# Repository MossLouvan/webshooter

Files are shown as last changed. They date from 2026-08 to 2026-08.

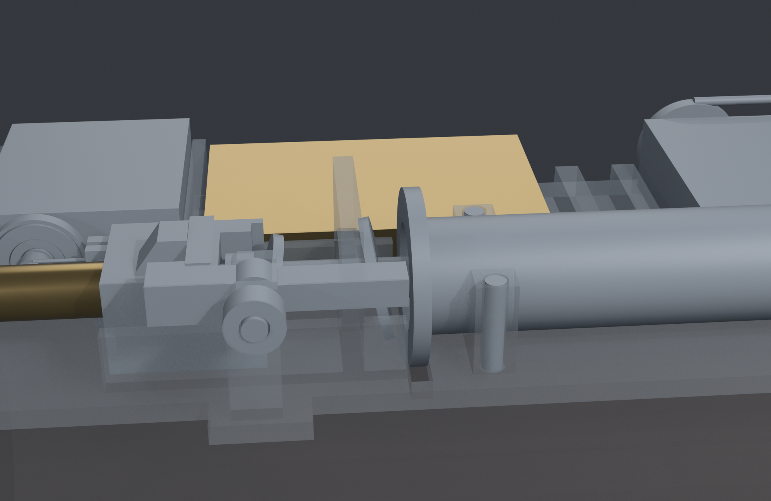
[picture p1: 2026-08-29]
mk2/mk5_02_mechanism.png

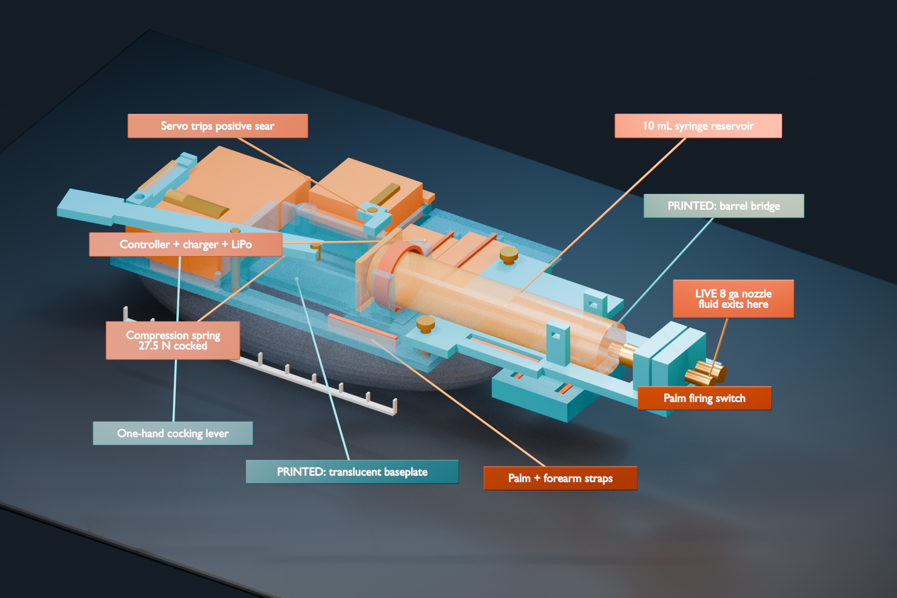
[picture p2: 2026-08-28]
mk2/mk3_viz_01_hero.png

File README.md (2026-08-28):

# Web-Shooter

A wrist-worn device that sprays Beacon Fabri-Tac fabric adhesive to produce a
Spider-Man-style strand. Visual effect only — **it bears no load**.

> **Status: unbuilt, untested, and currently failing its own independent audit.**
> This is a design-in-progress published for reference. Nothing here has been printed,
> assembled, or fired. See [Known failures](#known-failures-mk4) before doing anything else.

## Safety — read before building

This device stores mechanical energy in a compressed spring and uses it to eject a jet of
acetone-thinned contact adhesive at several metres per second.

- **Acetone and Fabri-Tac vapour are flammable.** The mixture is a skin, eye and
  respiratory hazard, and Fabri-Tac bonds to skin. Mix and fire only with strong
  ventilation, away from all ignition sources, wearing sealed goggles, solvent-rated
  (butyl/nitrile) gloves and an organic-vapour respirator.
- **There is no mechanical safety and no firmware in this repo.** The Mk4 sear is
  self-holding; the only thing between the cocked spring and a discharge is a hobby servo
  horn. A servo power-up twitch, brownout, reset, or loose lead can fire it. Any build
  must add a physical sear block or trigger disconnect that is removed by hand, and must
  keep the battery disconnected whenever the spring is cocked and not about to be fired.
  A naively written firmware will fire on boot.
- **Never cock, load, or fire the device while it is on an arm.** Cock with two hands,
  off the arm, muzzle pointed at a disposable backstop. Peak cocking force is ~16 N on a
  4 mm printed tab that sits in the carriage path: if your thumb slips before the sear
  engages, the carriage snaps forward onto your fingers.
- Never point it at a person, animal, face, flame, vehicle or property. Store it uncocked
  (PETG creeps under sustained load and is **not** acetone-resistant; the sear is a
  life-safety part and its layer orientation matters).
- The LiPo has no retention in Mk4. Do not strap an unretained pouch cell against a
  moving carriage and a solvent reservoir; relocate or pocket it.

**No warranty.** This is an experimental personal project published for reference only.
It is not a product, has never been built or bench-tested, and has not been reviewed for
safety by anyone qualified. It is provided "AS IS", without warranty of any kind (see
`LICENSE`). You build, modify, or operate it entirely at your own risk, and the author
accepts no liability for any injury, damage, or loss.

## Layout

Everything lives in `mk2/` (the folder name is historical; it holds Mk3 and Mk4).

| File | What it is |
|---|---|
| `webshooter_mk4.py` | **Current.** Parameterized CadQuery model; exports STEP/STL + `mk4_params.json` |
| `webshooter_mk2.py` | Previous Mk3 model (filename retained from the rebuild target) |
| `verify_independent.py` | Audit harness not written by the geometry author; reprobes the exported solids |
| `mk4_indep.json`, `indep_quick.json` | Independent-audit output for Mk4 / Mk3 — including the failures |
| `DESIGN_NOTES.md` | Design decisions, force and velocity arithmetic, unverified values |
| `BOM_DELTA.md` | What must be bought |
| `*_BRIEF.md` | Design/rebuild briefs written for and with AI coding agents during development; kept for provenance |
| `bl.py`, `build_mk4_viz.py`, `build_blender_viz.py` | Blender scene builder + headless CLI |
| `printed_parts/`, `assembly_stl/`, `mk4_*.stl/step` | Generated geometry |

## Mk4 (current)

Open frame: a curved baseplate strapped to the forearm with components mounted exposed
on top, and a muzzle extending over the back of the hand. A 5 mL syringe acts as
reservoir, pump and seal in one part. A hand-cocked spring is held by a self-holding sear
and released by a hobby servo. Mk4 cut the Luer fitting, the cocking lever and its pins.

**Targets:** ≤25 mm wrist profile · ≥1.5 mL per shot · ≤6 printed parts · ≥1.5 m throw.

### Known failures (Mk4)

`verify_independent.py` on the committed Mk4 geometry reports these; none are fixed yet:

- `baseplate <> switch_pod` overlap 255.95 mm³; `baseplate <> sear` 150.00 mm³;
  `baseplate <> outlet_adapter` 85.88 mm³; `baseplate <> carriage` 18.90 mm³
- carriage → baseplate: 18.90 mm³ interference **at 0.00 mm of travel** (it jams before it moves)
- unsupported islands on baseplate (50.7 mm²), carriage (21.5), outlet_adapter (50.8), switch_pod (60.0)
- with the real 8 ga needle (ID 3.429 mm) the shot needs 0.1705 J but the spring stores 0.1335 J
  — **the design does not have the energy to fire as specified**

Unmodelled and known-doubtful: syringe seal breakaway friction (can consume the whole spring
force), a linear spring that falls below the 5.6 N plunger force at ~11 of 16 mm of stroke
(only ~1.3 mL of 2 mL leaves at pressure), and a 0.5 Pa·s viscosity guess for thinned,
non-Newtonian adhesive. All range figures are indicative only.

## Reproduce

```bash
pip install cadquery                              # Python 3.12 required
python mk2/webshooter_mk4.py                      # writes STEP/STL + mk4_params.json
python mk2/verify_independent.py --quick          # independent audit (defaults to Mk4)
python mk2/verify_independent.py --model webshooter_mk2   # audit the Mk3 model
blender -b --python mk2/build_mk4_viz.py          # Blender 5.2 scene
```

The verifier exits via `os._exit` because CadQuery/OCCT can segfault at interpreter teardown.

## Design history

Mk1 was an enclosure around a 10 mL fragrance pump. Three independent audits found it
over-packed (96% cabin fill), geometrically broken in three parts, and functionally
doubtful — a 0.1 mL dose cannot form a strand. Scrapped and removed from the tree.

Mk2 replaced it with an open frame and a syringe, hitting the size and volume targets,
but audits found the chosen linear actuator was ~100× too slow: for a positive-displacement
pump, exit velocity is fixed by kinematics alone, and a 210:1 gearbox and a jet are
mutually exclusive. Mk3 replaced the drive with a spring and sear; its self-check passed
while the independent harness found jams and overlaps. Mk4 is the response, and still fails.

**Lessons worth keeping:** compute exit velocity and range, not just shot volume; size the
spring on force at end of stroke, not stored energy; do not trust a model's own self-check.

## Requirements

- Python 3.12 + CadQuery 2.8 (`pip install cadquery`)
- Blender 5.2 for visualization (`bl.py` looks for it at the default Windows install path;
  edit `DEFAULT_BLENDER` otherwise)
- CQ-editor for interactive viewing (`pip install cq-editor`), optional

Print in PETG for load-bearing parts (creep resistance; it is not acetone-proof — keep the
solvent path off the printed parts); PLA is fine for fit-test coupons only.

## `bl.py` — Blender scene CLI

Drives a `.blend` headlessly (defaults to the Mk3 visualization; pass `--blend
mk2/webshooter_mk4.blend` for Mk4). Note that `show/hide/isolate/reset` save the file.

```bash
python mk2/bl.py stats                  # counts, bounds, frame range, markers, cameras
python mk2/bl.py ls                     # every object: collection, dims, location
python mk2/bl.py tree                   # collection hierarchy
python mk2/bl.py info sear              # full dump for matching objects
python mk2/bl.py measure syringe sear   # min vertex gap + bbox gap + centre distance
python mk2/bl.py isolate baseplate      # show only these
python mk2/bl.py render --cam hero --frame 46 --res 1920x1280
python mk2/bl.py shot --az 135 --el 20  # render from an arbitrary angle
python mk2/bl.py turntable --frames 24  # orbit sequence
python mk2/bl.py export --fmt glb --only printed
```

Names match loosely: case-insensitive, punctuation-insensitive substrings, and
collection names work anywhere an object name does. `--dry` prints the generated
Blender script instead of running it.

## License

MIT — see `LICENSE`. The disclaimer above applies to the hardware design as well as the code.

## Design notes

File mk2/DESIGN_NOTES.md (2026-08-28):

# Web-Shooter Mk3 design notes

## Exit velocity and range — governing calculation

Mk3 uses a hand-cocked compression spring, a positive sear, and an owned Corona DS239MG servo only to release the sear. The Actuonix L12, Pololu U3V70F6 and DRV8833 are deleted.

For any positive-displacement syringe, force and viscosity do not set the kinematic ceiling. Plunger speed and area ratio do:

```text
10 mL syringe bore               d_p = 15.9 mm
plunger area                     A_p = pi d_p^2 / 4 = 198.556 mm2
3.0 mm effective outlet area     A_o = pi (3.0)^2 / 4 = 7.069 mm2
area ratio                       A_p/A_o = 28.080

2.000 mL stroke                  x = 2000 / 198.556 = 10.073 mm
selected shot time               t = 0.069 s
mean plunger speed               v_p = x/t = 0.14599 m/s
exit velocity                    v_exit = v_p(A_p/A_o) = 4.101 m/s
ideal level 45 degree range      R = v_exit^2/g = 1.715 m
```

The 69 ms shot is deliberate. The rebuild brief's illustrative 0.5 s shot would give only 0.566 m/s and an ideal ballistic range of 0.033 m. Even the final 250 ms limit gives only 1.13 m/s and 0.13 m ideal range. Therefore the explicit **>=1.5 m ballistic target** governs and requires no more than about 74 ms for 2 mL through a 3 mm outlet. Mk3 carries 14.3% ideal-range margin and 181 ms time margin to the hard limits.

The range value is the drag-free 45 degree upper bound, not a promise for adhesive in air. Real strand range must be measured outdoors into a safe backstop. The calculation is printed on every generator run and stored in `verification_report.json` so a slow drive can never pass silently again.

## Fluid and spring sizing

Beacon's Fabri-Tac SDS publishes 8,000 cP (8.0 Pa·s) for the neat adhesive. Mk3 uses the permitted **1:1 Fabri-Tac/acetone starting mixture**. The brief's measured guidance is that this reduces shear viscosity about 16x, to roughly 0.5 Pa·s, while polymer extensional elasticity preserves stringing and acetone flash-off reconcentrates the strand.

The source spring is selected from the owned/buying compression-spring assortment by measurement, not by color or appearance:

```text
maximum OD                     10.0 mm
free length                    39.7 mm
spring rate                    1.94 N/mm
fired installed length         35.6 mm
cocked installed length        25.53 mm
fired preload                  7.95 N
cocked force                   27.50 N
releasable energy              0.179 J
lever mechanical advantage     2.06:1
maximum ideal hand force       13.35 N
```

The releasable energy is below the verifier's 0.25 J safety ceiling. It is enough for the short, wide 8 ga/Luer path only after 1:1 thinning; it is not permission to install a stiffer spring. Bench-select the spring with the multimeter-sized scale/force fixture described below, then confirm 2 mL discharge in <=69 ms with high-frame-rate video. If the measured shot is slower, reduce restriction and seal friction before changing spring energy.

The live nozzle mockup uses the real nominal 8 ga OD of 4.19 mm and a conservative 3.0 mm effective outlet. The capped upper nozzle is visual symmetry only. The syringe Luer, live hub, metal nozzle, and both bridge bores share the named axis `(y=-6.0, z=12.5)`; the verification report asserts 0.000 mm axis and axial connection error.

## Mechanical architecture

Six printed parts are generated:

1. `baseplate` — flat-printing 2.8 mm shallow chord with a continuous perimeter, broad device floors, two forearm strap pairs, spring reaction wall, 24 mm-wide carriage way, open electronics anchors, syringe cradle, and bridge bosses.
2. `barrel_bridge` — continuous 32 mm deck with a 74 mm open syringe/Luer lane, 60 mm rear joint wing, outboard palm strap slots, forward syringe guide, and two bored barrel towers.
3. `spring_carriage` — broad anti-rotation tappet guided on both sides, with spring seat, full plunger pad, closed cocking-pin lug, and sear shoulder.
4. `cocking_lever` — one-hand lever with a 55 mm hand arm and closed M3 drive eye. Its deployed arc retracts the carriage through the full 10.073 mm stroke; the sear holds the load while the lever returns to the stowed position.
5. `servo_sear` — M3-pivoted, thickened around the pivot. The spring load closes into the base boss; the DS239MG horn only trips the unloaded tail.
6. `palm_switch_pod` — 2 mm floor under the owned 12 mm tactile switch, two bounded 26 mm strap slots, and lead-retention holes. It is held by the palm strap rather than floating from the hand.

The baseplate prints flat on its 7,435.6 mm² first layer. It is not a concave shell. Closed-cell neoprene supplies the conformal skin interface. The bridge joint has direct boss-to-deck contact at z=6.2 mm and two M3 heat-set inserts centered at x=112 mm, 6 mm inboard of the base end; no insert pocket breaks out and there is no clamped air gap.

The bridge lane leaves two 6.75 x 3.0 mm continuous side rails through the syringe zone: 40.5 mm² total section before the wider wings and tower roots. This replaces Mk2's two 0.75 mm ligaments. The rear and forward syringe guides have 0.60 mm radial clearance and explicit EPDM retainer geometry. A low rear flange stop reacts the syringe body below the elevated carriage sweep. The complete finger flange is present in the syringe mockup.

The electronics stack is now only the owned 1S LiPo, XIAO ESP32C3, TP4056/DW01 charger, DS239MG servo, hard switch, and wiring. The pouch has a 0.60 mm floor gap, low corner keepers, and no top clamp. Each board rests 0.60 mm above a real floor and is held under an EPDM U-band in broad grooved anchors; USB ends stay open.

## Verification harness

`python webshooter_mk2.py` regenerates the part STEP/STL files, full assembly STEP, every assembly STL mockup, and `verification_report.json`. A passing run performs all of the following:

- prints exit velocity, ideal 45 degree ballistic range, volume, and shot time;
- checks exactly 2.000 mL, <=69 ms, >=1.5 m ideal range, <=0.25 J spring release energy, <=6 printed parts, and <=25 mm wrist profile;
- sweeps the carriage every 0.5 mm through 10.0 mm and at the exact 10.073 mm endpoint;
- checks both intersection volume and true minimum distance for every unordered assembly pair;
- rejects tangency for non-contact pairs and documents every allowed functional contact;
- requires `abs(z_min) < 0.0001 mm` in the real print orientation—there are no epsilon lifts;
- computes first-layer footprint from a real 0.20 mm slab;
- sections every part along X, Y, and Z at nine stations and rejects sampled areas below 2 mm² or sampled ligaments below 1.2 mm;
- tessellates each part, samples actual triangle normals, and reports down-facing area below 45 degrees above the build layer;
- checks straight fluid-path connectivity and tower-bore alignment;
- asserts a named source and envelope for every assembly mockup.

Latest clean audit values are written to the JSON rather than copied as untracked claims. The generated model has 6 valid single-solid parts, a 24.3 mm wrist-zone profile, a 0.400 mm worst-case swept static gap, and zero failures **from its own self-check**. The independent harness (`verify_independent.py --model webshooter_mk2`, output in `indep_quick.json`) disagrees and reports jams and overlaps; that disagreement is what drove Mk4, which still has open failures — see the README.

## Assembly and operation

1. Print the base, bridge, carriage, lever, sear, and switch pod in PETG using their exported local orientations. Do not rotate the base onto its old curved underside.
2. Heat-set the two bridge inserts; install the bridge with direct face contact. Confirm the live Luer/nozzle axis by sight before fitting adhesive.
3. Select and measure the spring. Reject any spring above 10 mm OD, 2.0 N/mm measured rate, 28 N cocked force, or 0.20 J measured release energy.
4. Fit the carriage between the two open rails, install the M3 cocking and pivot pins, and verify the carriage moves the full 10.073 mm by hand with the spring removed.
5. Fit the syringe under the EPDM guide retainer with its finger flange behind the low axial stop. The syringe must lift out after the retainer is released, allowing a second fill/shot after re-cocking.
6. Mount the DS239MG in its M3 cradle. Adjust the horn so it clears the sear except during a commanded trip. The servo must never hold spring load.
7. Route both forearm straps and the palm strap through all modeled slot pairs. The palm strap retains the switch pod.
8. Mix only a small 1:1 charge, away from ignition sources, with strong ventilation and eye protection. Acetone and Fabri-Tac vapors are flammable. Never aim the device at a person, animal, face, flame, vehicle, or property.

## Mandatory bench gates

- With the nozzle removed, confirm carriage travel is >=10.073 mm and no contact occurs at any intermediate position.
- With water, confirm 2.00 mL leaves in <=69 ms. Then repeat with a very small 1:1 adhesive charge into a safe disposable backstop.
- Measure spring force at fired and cocked lengths. Do not exceed the limits above.
- Confirm the LiPo cannot be compressed by straps or retainers and has clearance for swelling.
- Measure the actual owned TP4056, LiPo, switch, EPDM bands, spring and syringe flanges. Items marked `MEASURE` in the report must fit their conservative envelopes before printing the full base.
- Treat 1.715 m as an ideal ballistic ceiling. Record actual strand range and stop if atomization, splashback, clogging, frame cracking, sear bounce, or accidental release occurs.

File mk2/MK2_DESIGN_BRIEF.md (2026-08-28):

# Web-Shooter Mk2 — DESIGN BRIEF

**From:** Claude Code (Fable 5), 2026-08-27
**To:** Codex (full access)
**Status:** clean-sheet redesign. Mk1 is archived at `../archive_mk1/` and is **not** to be reused.

---

## 0. Why Mk1 was scrapped

Mk1 was an **enclosure containing a pump**. It grew to a 118 × 64 × 38 mm box because rigid parts
were stacked orthogonally and walls were wrapped around whatever the total came to. It also fired
only **0.1 mL per shot** (a fragrance pump's dose), which is roughly two orders of magnitude short
of what makes a visible strand. Three independent reviews found it over-engineered, badly packed,
and functionally doubtful.

**Mk2 is a different object: an open frame carrying a projector.**

The builder showed a reference build he wants to match — a flat plate strapped to the forearm,
components mounted exposed on top, and barrels extending forward over the back of the hand. No
shell. That silhouette is the design target, and it is not negotiable.

---

## 1. Design targets, in priority order

1. **Sleek.** Profile at the wrist **≤ 25 mm** above the skin. Nothing may look like a box.
2. **Functional.** It must deliver enough fluid to read as a strand, not a mist. Target
   **≥ 1.5 mL per shot** — at least 15× Mk1.
3. **Simple.** Target **≤ 6 printed parts**. Mk1 had 13.
4. **Buildable** by a student with a Bambu printer, hand tools, and the existing cart.

Where 1 and 2 conflict, say so explicitly and propose the trade rather than silently picking.

---

## 2. Architecture

**Open baseplate, no enclosure.** A curved plate that follows the dorsal forearm, ~3–4 mm thick,
with components bolted to its top face and left exposed. Cable runs and mechanism are visible —
that is the aesthetic, not a compromise.

**Three zones along the arm:**

| Zone | Location | Contents |
|---|---|---|
| Rear | forearm, x ≈ 0–90 | reservoir + drive mechanism |
| Mid | wrist, x ≈ 90–120 | electronics, kept thinnest — this crosses the flex point |
| Front | back of hand, x ≈ 120–190 | barrel bridge + barrels |

The **barrel bridge** is the signature feature. A narrow arm carrying the barrels forward over the
knuckles, so the barrels sit high and point where the hand points. The back of the hand is flat and
unused — exploit it. Keep the bridge narrow so it does not obstruct finger movement, and set the
barrel line so it clears the knuckles when the wrist is neutral.

**Two barrels.** Both are visible; at minimum one is live. Decide whether the second is live
(split flow, two strands) or a dummy for symmetry, and justify it. Symmetry is a legitimate reason
— this is a worn object.

**Straps, not a cuff.** Two strap slots in the baseplate for 25 mm webbing: one across the forearm,
one across the palm/hand. Delete the entire Mk1 elliptical-cuff apparatus. The baseplate's underside
should be a simple concave curve (dorsal forearm crown radius ≈ 50 mm) with a thin foam pad
assumed, not a fitted anthropometric shell.

---

## 3. Fluid system — the part that must actually work

**Use a syringe as reservoir, pump, and seal in one part.**

This is the key simplification. A syringe already is: a sealed reservoir, a positive-displacement
pump, a plunger seal, and a standard Luer outlet. Adopting it deletes the atomizer, both EPDM
glands, the M6 nut, the nozzle block's seal stack, the PTFE thread tape and the moving actuator —
i.e. every leak path in Mk1.

- **Reservoir:** a 10–20 mL plastic syringe, laid along the forearm. Must be **PP/PE with no rubber
  plunger tip** — acetone swells rubber. Parameterize barrel OD and length.
- **Outlet:** Luer taper → short PTFE or PP line → barrel. A blunt dispensing needle in the
  **1.0–1.5 mm** range is the physics-recommended orifice for a coherent jet; the 0.4 mm brass
  nozzle from Mk1 is explicitly **not** the plan (that orifice forces heavy dilution, and dilution
  is what destroys stringing).
- **Fluid:** Beacon Fabri-Tac, **undiluted or thinned no more than 1:0.5**. The concentration is
  what makes it string.

**Drive:** the servo pushes the plunger. The plunger needs tens of millimetres of travel, which a
short horn cannot give, so you need mechanical advantage — a long lever, a rack, a lead screw, or
a cam. **This is the single most important engineering decision in Mk2 and it is yours to make.**

Constraints and known data:
- Corona DS239MG: **4.6 kg·cm at 6 V**, and servodatabase lists its rotation as limited — verify
  and design conservatively. The builder owns **two**.
- Required plunger force is **unknown** and depends on syringe bore, fluid viscosity and orifice.
  Estimate it, show the arithmetic, and state the margin.
- **If the DS239MG cannot do it, say so and specify what to buy instead** (a higher-torque servo, a
  geared DC motor with a lead screw, or a linear actuator). A correct recommendation to buy a
  different actuator is a better outcome than a design that stalls.
- A one-shot-per-fill design is acceptable if it buys sleekness; a multi-shot ratchet is better.
  Choose and justify.

**Refill** must not require disassembly — the syringe should lift out or be reloaded in place.

---

## 4. Electronics

Carry over from Mk1, unchanged and already owned: **XIAO ESP32-C3**, **TP4056 USB-C with DW01
protection**, **EEMB 103454 LiPo**, **12 × 12 mm tactile switch**, 26 AWG silicone wire, JST-PH.
**No MT3608** — the boost was deleted and stays deleted unless your actuator choice forces it back,
in which case flag it loudly.

- Trigger: palm switch, **double-tap within 400 ms**.
- **Do not use GPIO8 or GPIO9** for the switch — GPIO9 is the boot strapping pin.
- A **power switch is required** and does not exist yet. Specify one and give it a mount.
- Boards have **no mounting holes** — design clips or captive pockets.
- USB-C on the TP4056 must be reachable for charging; the XIAO's USB-C must be reachable for
  flashing. On an open frame this is easy — do not squander it.

---

## 5. Deliverables

Work in `mk2/`. Do not touch `../archive_mk1/`.

1. **`webshooter_mk2.py`** — parameterized CadQuery model. Named constants at the top with a
   confidence comment on anything unverified. Exports one STEP and STL per printed part.
2. **A real assembly** — `cadquery.Assembly` with explicit transforms, plus **mockup solids** for
   every purchased item (syringe, servo with horn/lever, LiPo, XIAO, TP4056, switch, barrels,
   straps, and a forearm + hand reference) so the assembly shows how it works. Mockups in a
   separate dict, never exported as printable.
3. **`assembly_stl/`** — every part at its assembly transform, for rendering.
4. **`DESIGN_NOTES.md`** — the actuator decision with its force arithmetic, the profile height
   achieved, part count, what is proxy/estimate/unverified, and a measure-before-printing list.
5. **`BOM_DELTA.md`** — exactly what must be **bought that the builder does not already own**, with
   quantities and why each is needed. Be specific and minimal. He already owns everything in §4
   plus Fabri-Tac, acetone, PTFE tube, EPDM assortment, M3 screws, M3 heat-set inserts (5.0 × 4.0),
   4 × 2 mm magnets, brass 0.4 mm nozzles, glass atomizers, dropper bottles, butyl gloves,
   respirator, goggles.

## 6. Hard requirements — these will be checked

- Every printed part: **exactly one solid**, `isValid()`, and no geometry below its own z = 0.
- **No unintended interference.** Run a pairwise intersection check across all parts *and* mockups
  and report the volumes. Intended contacts must be listed explicitly with a reason. Assume a
  reviewer will run this check without your allow-list — Mk1's did, and found 18 pairs.
- Every mating feature must exist on **both** sides, driven by **shared named constants**. No
  duplicated coordinate literals.
- No declared-but-unused parameters.
- Wrist profile height stated and ≤ 25 mm.
- Shot volume stated and ≥ 1.5 mL.

## 7. Latitude

The zones, the syringe, and the barrel bridge are the concept. **Everything else is yours.** If a
different drive mechanism, a different reservoir, or a different part split serves the three targets
better, take it and explain why. If you conclude a target is unachievable, say which one and what it
would cost to reach — do not quietly miss it.

Three independent reviewers will audit this build and will keep auditing until they have no
substantive findings. Design for that.

Work autonomously. Do not stop to ask questions.

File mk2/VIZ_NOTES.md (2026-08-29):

# Web-Shooter Mk5 visualization

`webshooter_mk5.blend` is a Cycles product-presentation scene generated from
the transformed STLs in `mk5_assembly_stl/`. It opens at the cocked/ready frame
with the labeled hero camera active.

## Presentation design

- Satin/brushed steel distinguishes printed working structure; warm polished
  brass identifies the spring, plunger interfaces, and muzzle.
- The cartridge uses transmissive borosilicate glass. Frosted translucent PETG
  keeps the chassis readable without hiding the mechanism.
- Electronics use graphite polymer, LiPo foil, and green FR4/solder-mask
  materials. The palm switch is matte red rubber.
- Every imported STL has a 0.4 mm, three-segment highlight bevel.
- A four-light studio rig, low-strength environment, and smooth charcoal
  cyclorama provide soft contact shadows and controlled metal/glass reflections.
- The label-free beauty camera uses restrained depth of field. The technical
  camera is fully sharp and retains short, staggered, part-following leaders;
  the baseplate label remains below the device.
- The mechanism camera views the sear/pawl from the open side so the dark servo
  does not wall off the working interface.

## Outputs

- `mk5_00_beauty.png` — label-free portfolio hero.
- `mk5_01_hero.png` — labeled technical hero.
- `mk5_02_mechanism.png` — sear/pawl and spring-drive close-up.
- `mk5_03_plan.png` — top-down assembly layout.
- `mk5_04_firing.png` — fired state and fluid pulse.

All final stills are 2560 × 1600, rendered in Cycles at 256 samples with
denoising and AgX medium-high contrast.

## Regenerate

```powershell
& 'C:\Program Files\Blender Foundation\Blender 5.2\blender.exe' -b --python '.\build_mk5_viz.py'
```

The generator requests OptiX first, CUDA second, and reports a CPU fallback if
neither GPU backend initializes. For quick beauty look-development, set
`MK5_LOOKDEV=1`. To render only one named output, set `MK5_VIEW` to its filename
stem, for example `mk5_02_mechanism`.

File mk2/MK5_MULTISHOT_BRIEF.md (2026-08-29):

# Mk5 — MULTI-SHOT BRIEF

**Status:** Mk4 was rejected NOT READY by two independent acceptance reviews. The builder has
independently identified the same top defect: **it fires once and does not return.** He wants a
mechanism that shoots, re-cocks itself, and shoots again.

This brief is the fix list plus the new requirement. Read it whole before editing anything.

---

## 1. THE NEW REQUIREMENT — multi-shot with self-recock

**Mk4 fires exactly one useful shot per fill, and nobody noticed until two reviewers and the
builder found it separately.** The carriage cocks to a fixed x=31.57 and fires to a fixed x=48.00.
After shot 1 the syringe plunger has advanced 16.43 mm and sits at x=60.00 — beyond anywhere the
carriage can reach. Shot 2 pushes air.

**Mk5 must fire, re-cock, and fire again, repeatedly, until the cartridge is empty.**

### This is a caulk gun

The problem is exactly the one a caulk gun solves: a **fixed-stroke actuator advancing a plunger
incrementally through a one-way grip.** The plunger never retracts — it does not need to. Each
cycle the carriage grips the rod further back, drives it forward one stroke, then releases and
slides back along the now-stationary rod to grip again.

Adopt that. A tilting grip plate, a ratchet and rack, or a one-way roller clutch are all valid;
pick one and justify it. The grip must hold 37 N forward and release cleanly on the return.

### Shot count is a cartridge-size decision

| Cartridge | shots at 2.0 mL |
|---|---|
| 5 mL (Mk4) | 2.5 |
| **10 mL** | **5** |
| 20 mL | 10 |

Mk4 went 10 mL -> 5 mL to cut force and height. With a ratchet the force argument weakens, because
the servo can do the work. **Re-open that choice.** If you go back to 10 mL, say what it costs in
wrist profile and re-check the target (<= 25 mm).

If you reduce shot volume to gain shots, the outlet bore must shrink to hold exit velocity —
`A_o = V / (t · v_exit)`. 1.5 mL -> 3.46 mm bore; 1.0 mL -> 2.83 mm. Do not silently lose range.

### Auto-recock is affordable — I checked before asking

```
recock work            = ½ · 37.42 N · 16.43 mm = 307 N·mm = 0.307 J
DS239MG stall           = 451 N·mm   (4.6 kg·cm at 6 V)
honest continuous (⅓)   = 150 N·mm

torque needed vs servo sweep:
    90°  -> 196 N·mm   too much
   120°  -> 147 N·mm   marginal
   160°  -> 110 N·mm   1.4× margin
   180°  ->  98 N·mm   1.5× margin
```

**A generous sweep (160–180°) through a cam or lever makes recock feasible with the servo he already
owns.** Verify the DS239MG's actual usable rotation — servodatabase lists it as limited, and if it
cannot sweep 160° this whole approach changes.

---

## 2. THE SEAR PROBLEM, AND THE ARCHITECTURE CHOICE

Both reviewers computed the sear release torque, which nothing had ever computed:

```
holding moment  |r_z| · F = 13.4 × 37.42      = 501 N·mm
face friction   µ · F · |r_x| = .35 × 37.42 × 9 = 118 N·mm
pin drag                                       ≈  18 N·mm
                                       total  ≈ 520–620 N·mm
```

against ~150–300 N·mm from the servo. **The over-centre sear is too self-holding to open.** Being
strongly self-holding and being openable are the same axis, and Mk4 maximised the wrong end.

Three architectures. Choose one, justify it, and say what you gave up:

**A — Cam cock-and-release, no sear at all.** The servo sweeps once: the cam draws the carriage
back, and at the drop-off point releases it. Simplest, deletes a printed part and the entire
release-torque problem. **Cost:** a ~1 s wind-up between trigger and shot — you lose the instant
thwip, which is most of the appeal.

**B — Near-pivot sear (recommended starting point).** Move the contact onto the pivot line so
`r_z ≈ 0`. Holding moment collapses toward zero and release becomes **friction-only**, tens of
N·mm. It is then no longer self-holding, so it needs a light return spring to keep it engaged —
which is what every real firearm sear has. Keeps the instant shot; costs one spring.

**C — Hand-cocked ratchet.** The builder cocks between shots; the servo only trips. Simplest and
most reliable, but it is not what he asked for.

**B is the recommendation.** A reviewer proposed it independently: *"a simpler transverse sear
bearing near the pivot line — so the release torque is friction only."*

---

## 3. BLOCKING DEFECTS TO FIX (all measured, not inferred)

| # | Defect | Evidence |
|---|---|---|
| 1 | **Single-shot** | above — the headline |
| 2 | **Servo cannot open the sear** | 520–620 N·mm needed vs ~150–300 available |
| 3 | **No servo interface exists anywhere** | `grep servo` finds only comments. No mount, horn, pushrod or linkage. `BOM_DELTA.md` says "servo mounting as shown"; nothing is shown |
| 4 | **Plunger thumb flange does not fit** | Ø18.0 vs 14.90 mm rail clear span. 385 mm³ into the carriage, 31.85 mm³ into the baseplate |
| 5 | **Finger flange buried in the plate** | 115.60 mm³ |
| 6 | **Spring force 24% above every downstream number** | it seats on the abutment FRONT face at x=6.0, not x=8.0. True cocked force **37.42 N**, not 30.09. The docstring still claims an 11.2 N "thumb pull" |
| 7 | **Cartridge cannot be installed** | the drop-in opening is `2 × cradle_r × 0.72 = 10.30 mm` against a **13.70 mm** barrel |
| 8 | **Thrust path never lands on a face** | the stop is bored r=9.35; the adapter is r=9.05 and passes through it. ~10–30 N per shot goes into a glue joint and an insert-boss corner |
| 9 | **Carriage has no vertical retention** | 3.25 mm of free lift on a wrist-worn device |
| 10 | **Bore clogs permanently** | 151 mm³ of adhesive in an open 4 mm bore; clearing a cured plug needs ~151 N against 30 N available. The adapter is *bonded*, so there is no disassembly path. **Design a purge or a serviceable joint** |
| 11 | **Spring buckling** | L/D = 6.48 at 0.357 deflection, pinned-pinned. Needs a pilot or a guide tube |
| 12 | **Half-cock is not held** | abort a cock and the spring cams the pawl open and throws the carriage. It can catch a finger between the pad and the plunger flange |
| 13 | No fillets or chamfers anywhere | one `fillet` token in the whole file, in a comment. Every edge on a 172 mm plate worn against an arm is a printed square corner |

---

## 4. THE HARNESS — how this was missed, and the rule

`verify_independent.py` guards its mockup load with `if hasattr(M, "mockups")`. Mk4 defined none,
so the guard silently skipped and `bodies` held only the five printed parts. Every defect above
lives at a printed-to-purchased interface. A reviewer's phrasing: **"the harness was not gamed by
editing — it was starved by the model."**

`make_mockups()` now exists and the harness sees 7 real overlaps where it saw 0.

**RULES, absolute:**
- **Never** delete or narrow `make_mockups()` to make a failure disappear. Every body the machine
  touches belongs in it — and that now includes the servo, its horn and any linkage you add.
- **Never** loosen a threshold or grow `TOUCH_OK` to pass. If a check is a genuine false positive,
  prove it with measured geometry and fix the check.
- **Add checks for what you build.** A ratchet needs a check that it holds forward and releases on
  return. A servo linkage needs a **torque** check — there is not one load, stress or torque check
  in 1000+ lines, which is why defect 2 survived four revisions.

---

## 5. WHAT MUST NOT REGRESS

- exit velocity 3.84 m/s, ballistic range >= 1.5 m, shot volume >= 1.5 mL, all **derived**
- energy margin > 1.0 against the **real 8 ga cannula** (0.170 J), not just the 4 mm bore
- every printed part: exactly one solid, valid, `z_min ≈ 0`
- wrist profile <= 25 mm
- the sear kinematics that finally work — both reviewers confirmed the holding sign, the 24 mm²
  bearing patch and the self-camming re-cock ramp are correct. **Keep what works.**

## 6. DESIGN INTENT

Sleek but not sterile. The mechanism stays visible because it is worth seeing. This should read as
a considered instrument someone built — not a consumer product, and not parts bolted to a board.
Keep the part count honest: adding a ratchet is justified because it buys multi-shot; adding
anything that merely solves a problem another choice created is not.

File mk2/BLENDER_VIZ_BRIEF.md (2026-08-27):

# Web-Shooter Mk3 — Blender Visualization Brief

**To:** Codex (full access)
**Goal:** a Blender scene the builder can open, spin, and understand — showing the finished
Mk3 device assembled, with every part named and every purchased component in place.

Blender **5.2.1** is installed at:
`C:\Program Files\Blender Foundation\Blender 5.2\blender.exe`
Run headless as `blender -b --python <script>.py`, or with a GUI as `blender --python <script>.py`.

---

## 1. What you are visualizing

The Mk3 web-shooter you just built in `webshooter_mk2.py`. Source geometry is the STL set in
`assembly_stl/` — **printed parts and purchased-part mockups, each already transformed into its
assembly position.** If any mockup is missing from that folder, export it first; the whole point of
this deliverable is showing the bought parts in place, not just the printed ones.

**Who it is for.** A university student who is going to build this thing. He has said, repeatedly
and fairly, that he wants to *see* how it works and what each piece does. He is not a CAD person.
Assume he will open the .blend, orbit it, click things, and expect that to teach him the machine.

---

## 2. Hard requirements

1. **A `.blend` file** in this directory that opens ready to look at — framed, lit, material
   preview shading on, nothing selected, no console errors.
2. **Every object named in plain language**, not `mockup_ds239mg_servo`. "Servo (fires the sear)"
   beats a part number.
3. **Printed vs purchased must be visually obvious at a glance.** Pick a scheme and be consistent.
4. **Text labels in 3D with leader lines to their parts**, positioned so they do not overlap each
   other or bury the model. This is harder than it sounds — a naive "label above each part" pile
   collapses into unreadable soup. Fan them, stagger them, or place them in a ring; whatever
   actually reads. Check your own renders and iterate until it is legible.
5. **Collections** so groups can be toggled: printed parts, purchased parts, labels, reference
   (arm/hand). Named so the outliner is self-explanatory.
6. **The chassis/baseplate should not hide the mechanism.** Transparency, a cutaway, or a section —
   your call, but the internals must be visible.
7. **At least three rendered PNGs** saved beside the .blend: an isometric hero, a plan view, and one
   more of your choosing that best explains the mechanism.

## 3. What would make it genuinely good

These are not required. Take them if they serve.

- **Show the mechanism moving.** The whole device is one motion: cock the spring, trip the sear,
  plunger drives forward, fluid leaves the barrel. A short timeline animation — even 60 frames of
  the plunger stroke and the sear release — would teach more than any static render. Keyframe it so
  he can scrub.
- **An exploded view** on a second frame range, or as a separate scene, so he can see the stack-up.
- **A callout for the fluid path** — the route from syringe to barrel is the thing most likely to
  confuse, and it is worth making legible on its own.
- **A scale reference.** A hand, a forearm, a ruler — something that makes 118 mm feel like a real
  size rather than an abstract number.

## 4. Latitude

**The above is the goal, not a recipe.** You know Blender's Python API and you can see the actual
geometry; I cannot. If a different presentation explains this machine better, build that instead
and say why in your notes. Specifically, you may freely choose: camera framing and lens, lighting
rig, materials and colour scheme, label typography and placement strategy, whether to animate,
whether to explode, and how to handle transparency.

Two things I would not change without a reason: **plain-language names**, and **purchased parts
visible in place**. Everything else is yours.

## 5. Deliver

- The `.blend`, the render PNGs, and the generator script (so it can be re-run after CAD changes —
  this model will keep changing, and a viewer that must be hand-rebuilt each time is dead weight).
- A short note in `DESIGN_NOTES.md` or a separate `VIZ_NOTES.md`: what you built, what you chose and
  why, and how to regenerate it.

Verify before you finish: open the .blend headlessly, confirm the expected object count, confirm no
part is missing, and look at your own renders. If a render is unreadable, fix it and render again —
do not ship the first one.

Work autonomously. Do not stop to ask questions.

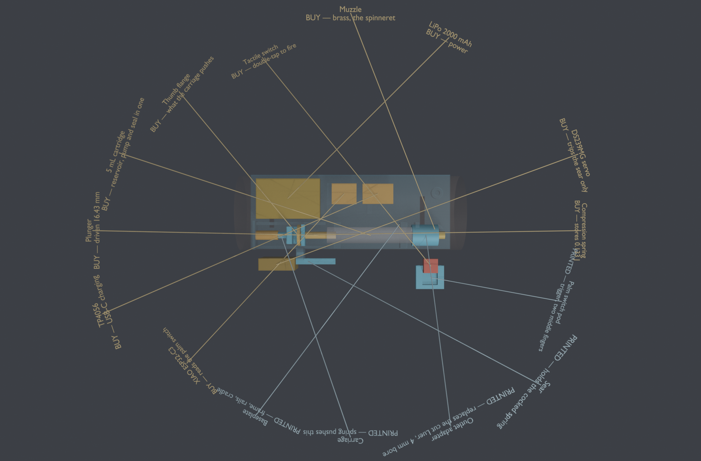
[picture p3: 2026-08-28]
mk2/mk4_02_plan.png

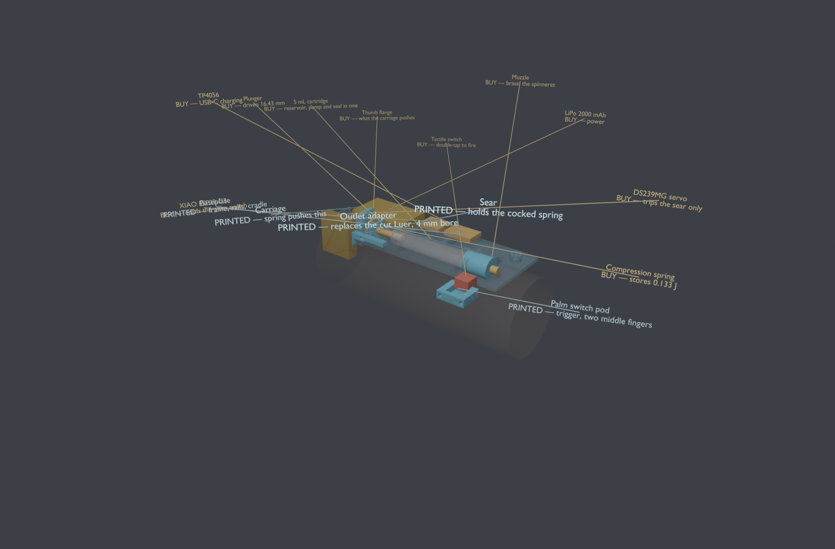
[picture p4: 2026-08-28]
mk2/mk4_01_hero.png

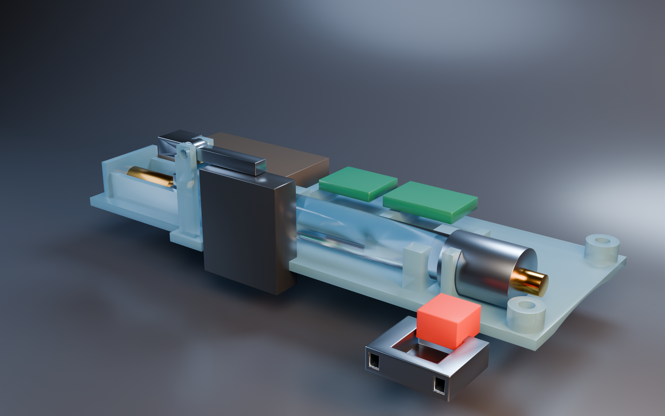
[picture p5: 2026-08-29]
mk2/mk5_00_beauty.png

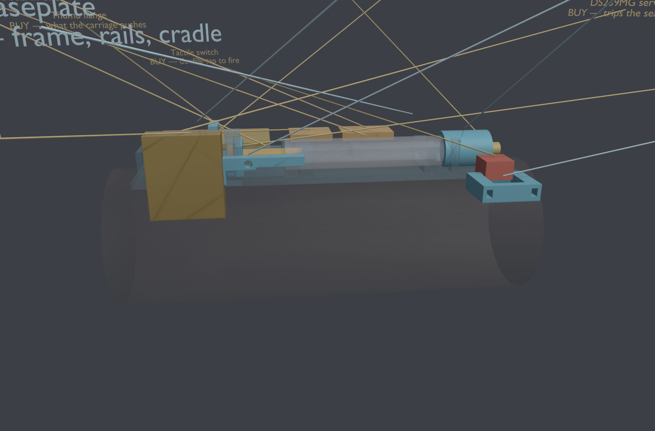
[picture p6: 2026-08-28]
mk2/mk4_03_mech.png

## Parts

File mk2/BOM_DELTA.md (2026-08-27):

# Mk3 buy-only BOM delta

**No additional purchase is required beyond the inventory and updated cart stated in `MK3_REBUILD_BRIEF.md`.**

## Deleted from the Mk2 purchase list

| Qty removed | Item | Reason |
|---:|---|---|
| 1 | Actuonix L12-10-210-6-S | A 210:1 gearbox cannot deliver the required plunger speed. Even its no-load kinematic ceiling dribbles. Replaced by a hand-cocked spring and sear. |
| 1 | Pololu U3V70F6 fixed 6 V boost | It existed only for the deleted linear actuator. |
| 1 | DRV8833 carrier | It existed only to reverse the deleted linear actuator. |
| 1 | Separate NORM-JECT syringe purchase | The updated cart already contains 10 mL Luer-lock syringes. Verify the actual bore/OD/flanges against the sourced envelope before printing. |
| 2 | Separate 14 ga needle purchase | The updated cart already contains an 8/10/12/14 ga blunt-needle assortment. Mk3 uses one live 8 ga nozzle and one capped 8 ga dummy. |
| 2 | Separate 25 mm straps | The updated cart already contains 1 inch hook-and-loop strapping. |
| 1 | Separate slide-switch purchase | The builder already owns tactile switches; the required hard battery disconnect remains an owned-item wiring gate. If the owned stock lacks a DC-rated disconnect, add one only after measuring it and update the CAD envelope. |

## Inventory consumed by Mk3

| Qty | Owned / already buying | Use |
|---:|---|---|
| 1 | Corona DS239MG servo | Trips the unloaded sear; does not drive the syringe or hold spring force. |
| 1 | Compression spring selected from assortment | OD <=10 mm, free length about 39.7 mm, measured rate 1.94 N/mm, <=28 N cocked, <=0.20 J measured release energy. |
| 1 | 10 mL Luer-lock syringe | 15.9 mm modeled bore; complete barrel, finger flange, plunger rod and thumb flange are included in the assembly mockup. |
| 2 | 8 ga blunt needles | One live 3.0 mm-effective outlet and one capped visual dummy. |
| 1 each | XIAO ESP32C3, TP4056/DW01, 1S LiPo | Logic, protected charging, and power. No motor driver or actuator boost. |
| 3+ | M3 screws; 2 M3 heat-set inserts | Bridge joint, carriage/cocking pin, sear pivot and servo mounting as shown. Final screw lengths must match the actual owned hardware. |
| As needed | EPDM O-rings/bands | Syringe and board retention in modeled grooves/anchors. |
| As needed | 1 inch hook-and-loop strap | Two forearm loops and one palm/switch-pod loop. |
| Small batch | Fabri-Tac and acetone | 1:1 starting mixture only, with ventilation and ignition control. |
| 6 parts | PETG | Base, bridge, carriage, cocking lever, sear and switch pod. |

Do not substitute a stiffer spring to chase range. The generator rejects more than 0.25 J modeled release energy, and the build notes impose a lower 0.20 J measured spring-selection gate.

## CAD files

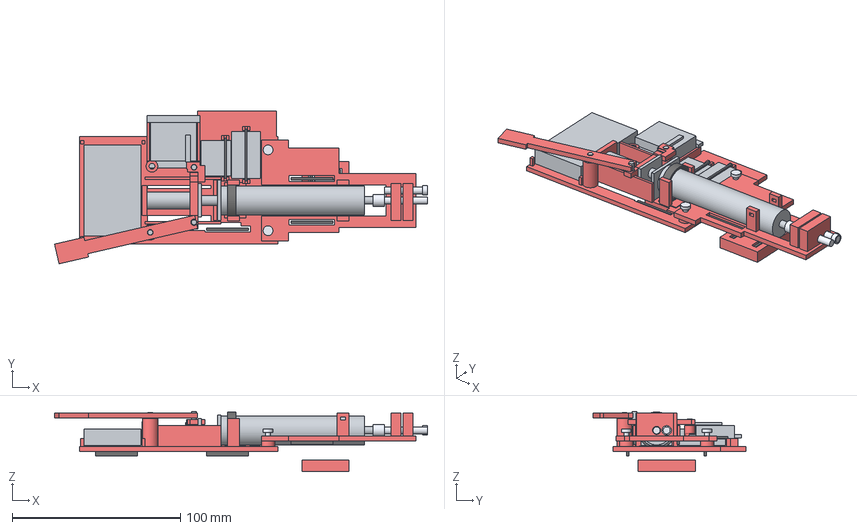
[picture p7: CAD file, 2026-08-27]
mk2/webshooter_mk2_assembly.step
221.6 x 90.7 x 35.8 mm
printed_baseplate
printed_barrel_bridge
printed_spring_carriage
printed_cocking_lever
printed_servo_sear
printed_palm_switch_pod
mockup_syringe_norm_ject_10ml
mockup_live_8ga_blunt_nozzle
mockup_capped_dummy_8ga_nozzle
mockup_selected_compression_spring
mockup_corona_ds239mg_servo
mockup_ds239mg_horn
mockup_lipo_eemb_103454_rotated
mockup_tp4056_usbc_dw01
mockup_seeed_xiao_esp32c3
mockup_tactile_switch_12mm
mockup_bridge_m3_screw_1
mockup_bridge_m3_insert_1
mockup_bridge_m3_screw_2
mockup_bridge_m3_insert_2
mockup_cocking_pivot_m3
mockup_cocking_drive_m3
mockup_sear_pivot_m3
mockup_tp4056_epdm_retainer
mockup_xiao_epdm_retainer
mockup_syringe_epdm_retainer
mockup_forearm_straps_25mm
mockup_palm_strap_25mm

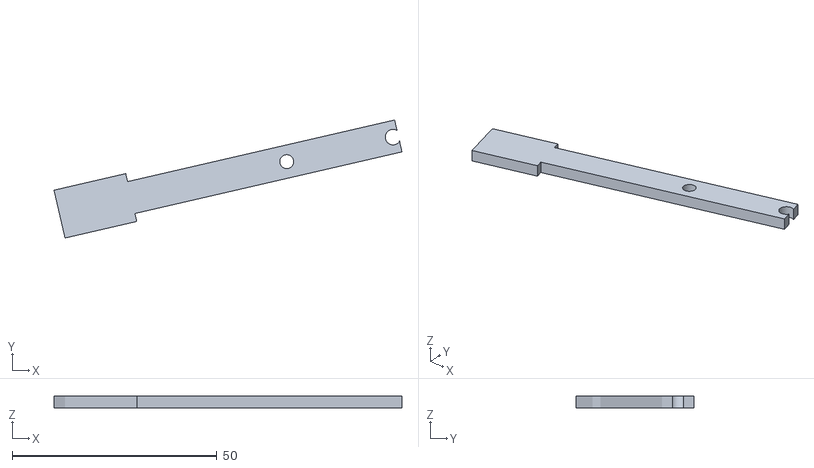
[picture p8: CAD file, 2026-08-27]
mk2/assembly_stl/printed_cocking_lever.stl
85.1 x 28.9 x 3.00

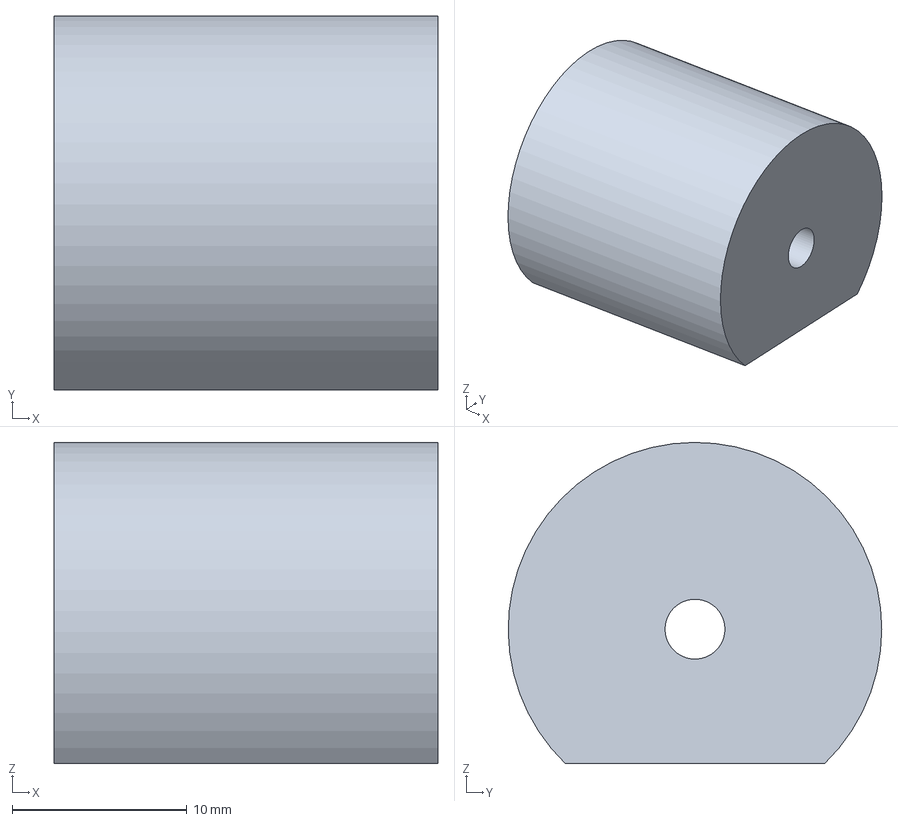
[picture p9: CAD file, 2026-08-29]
mk2/mk4_outlet_adapter.step
22.0 x 21.4 x 18.4 mm

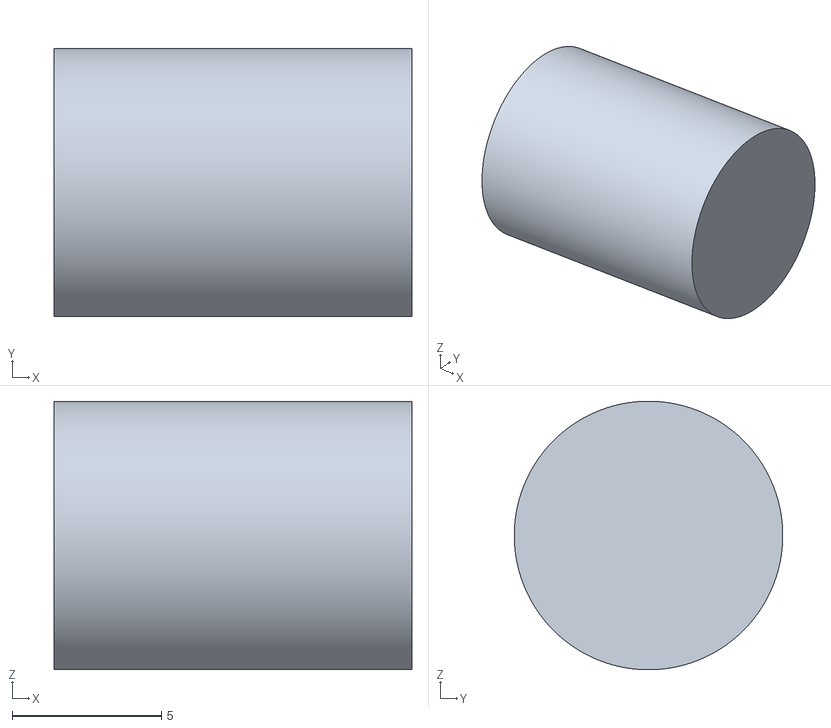
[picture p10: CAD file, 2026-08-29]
mk2/mk5_assembly_stl/mock_cannula_hub.stl
12.0 x 9.00 x 9.00

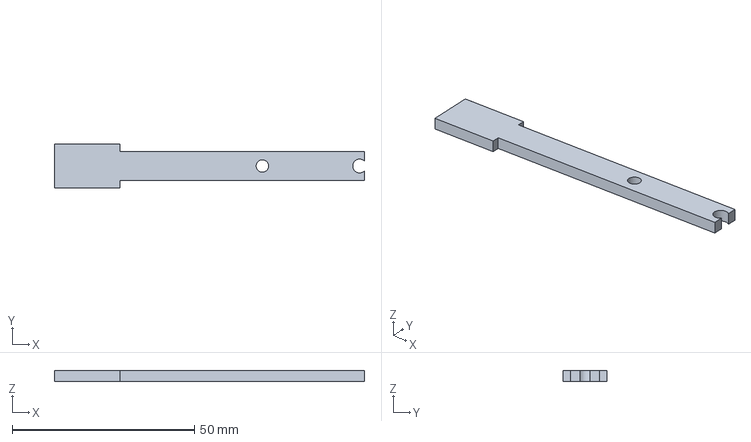
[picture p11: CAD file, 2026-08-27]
mk2/printed_parts/cocking_lever.step
85.0 x 12.0 x 3.00 mm

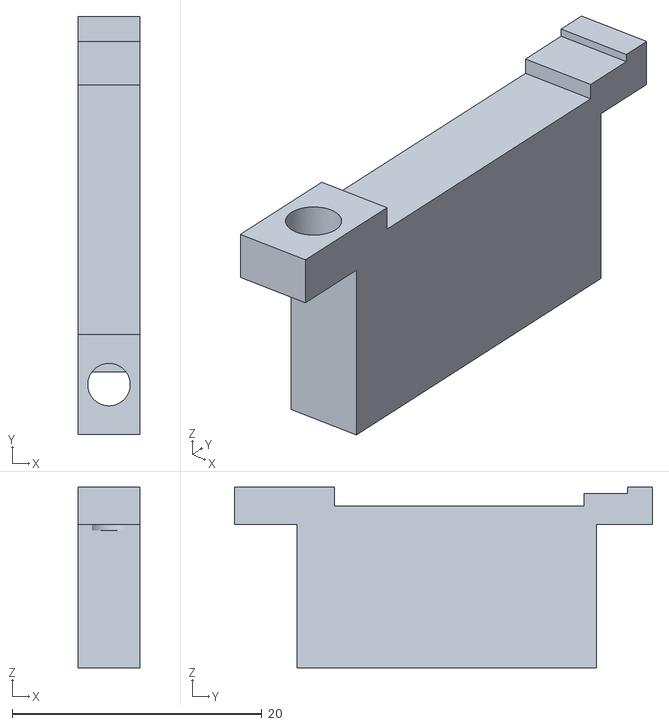
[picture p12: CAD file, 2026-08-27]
mk2/assembly_stl/printed_spring_carriage.stl
5.00 x 33.5 x 14.5

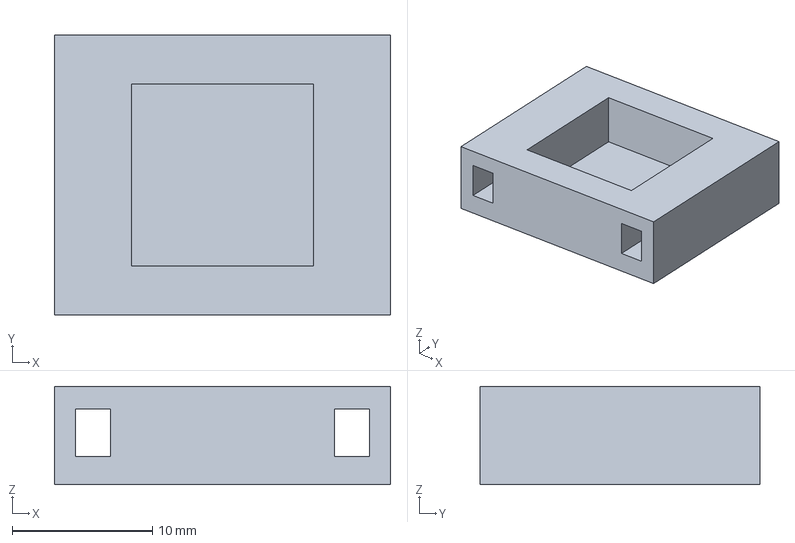
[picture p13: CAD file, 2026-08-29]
mk2/mk4_switch_pod.step
24.0 x 20.0 x 7.00 mm

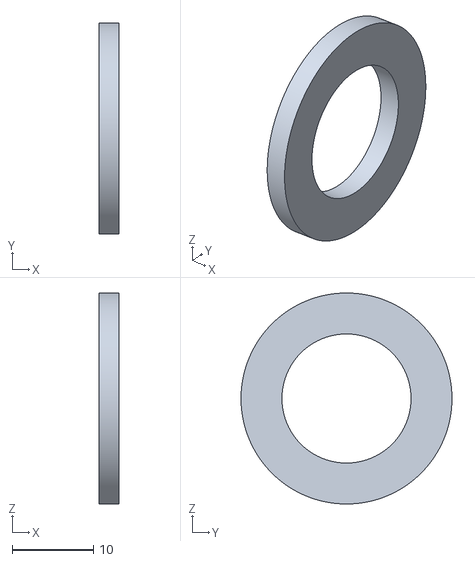
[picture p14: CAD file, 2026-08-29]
mk2/mk5_assembly_stl/mock_syringe_finger_flange.stl
2.50 x 26.0 x 26.0

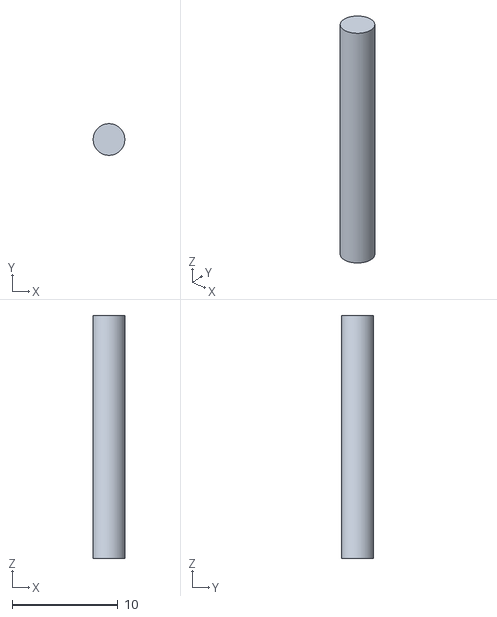
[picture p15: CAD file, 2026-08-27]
mk2/assembly_stl/mockup_cocking_pivot_m3.stl
3.00 x 3.00 x 23.0

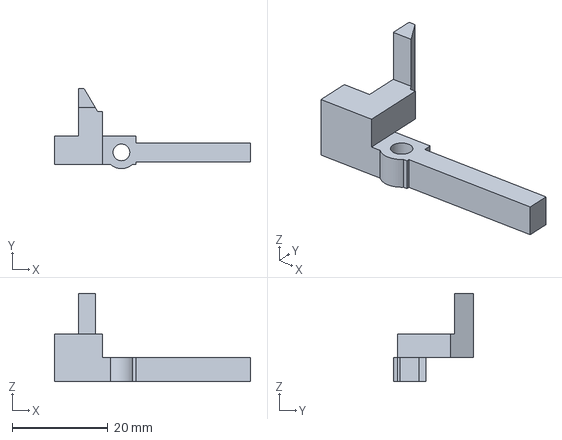
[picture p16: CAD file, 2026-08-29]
mk2/mk4_sear.step
41.0 x 16.8 x 18.4 mm

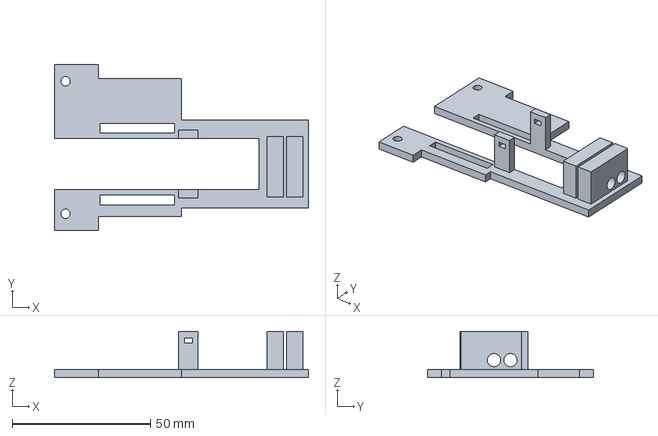
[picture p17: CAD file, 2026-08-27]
mk2/printed_parts/barrel_bridge.step
92.0 x 60.0 x 16.7 mm

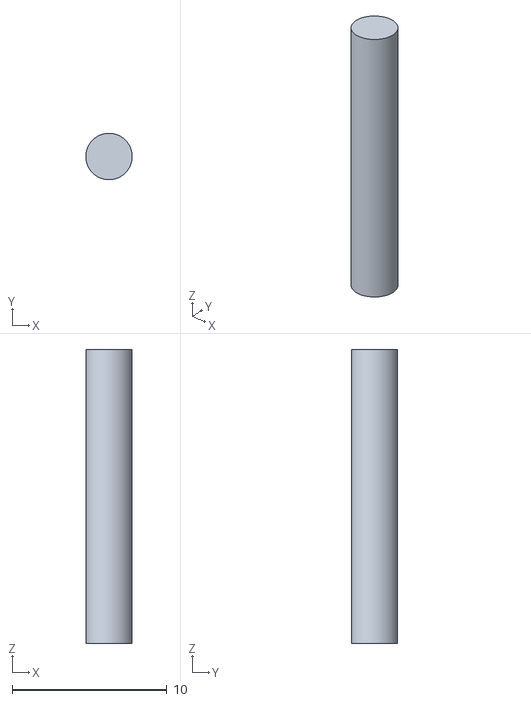
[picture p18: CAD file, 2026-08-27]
mk2/assembly_stl/mockup_sear_pivot_m3.stl
3.00 x 3.00 x 19.0

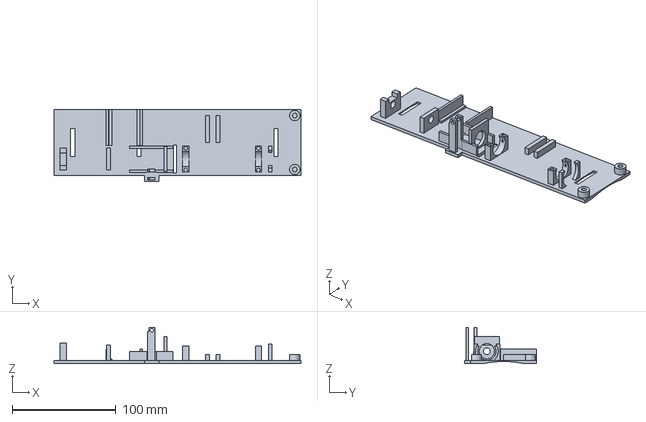
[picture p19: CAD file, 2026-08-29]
mk2/mk4_baseplate.step
238.0 x 69.8 x 35.1 mm

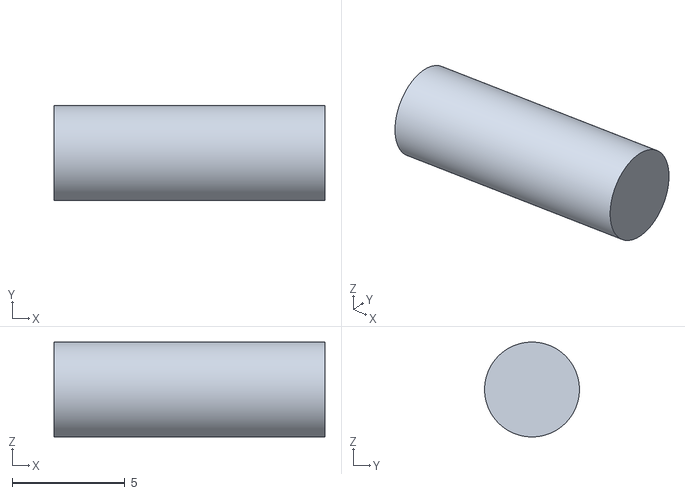
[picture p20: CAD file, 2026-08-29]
mk2/mk5_assembly_stl/mock_cannula.stl
12.0 x 4.20 x 4.20

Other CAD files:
mk2/printed_parts/spring_carriage.step
mk2/mk5_assembly_stl/print_outlet_adapter.stl
mk2/printed_parts/palm_switch_pod.step
mk2/assembly_stl/mockup_lipo_eemb_103454_rotated.stl
mk2/assembly_stl/mockup_bridge_m3_insert_1.stl
mk2/assembly_stl/mockup_bridge_m3_insert_2.stl
mk2/assembly_stl/mockup_bridge_m3_screw_1.stl
mk2/assembly_stl/mockup_bridge_m3_screw_2.stl
mk2/assembly_stl/mockup_capped_dummy_8ga_nozzle.stl
mk2/assembly_stl/mockup_cocking_drive_m3.stl
mk2/assembly_stl/mockup_corona_ds239mg_servo.stl
mk2/assembly_stl/mockup_ds239mg_horn.stl
mk2/assembly_stl/mockup_forearm_straps_25mm.stl
mk2/assembly_stl/mockup_live_8ga_blunt_nozzle.stl
mk2/assembly_stl/mockup_palm_strap_25mm.stl
mk2/assembly_stl/mockup_seeed_xiao_esp32c3.stl
mk2/assembly_stl/mockup_selected_compression_spring.stl
mk2/assembly_stl/mockup_syringe_epdm_retainer.stl
mk2/assembly_stl/mockup_syringe_norm_ject_10ml.stl
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

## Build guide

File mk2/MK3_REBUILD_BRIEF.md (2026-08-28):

# Web-Shooter Mk3 — REBUILD BRIEF

**To:** Codex (full access)
**Model:** `mk2/webshooter_mk2.py`
**Status:** three independent audits ran probes against your Mk2. All three returned BROKEN.
The open-frame concept, the zones, the bridge, the syringe-as-reservoir idea and the electronics
stack all survive. **The drive does not.**

---

## 1. THE FATAL FINDING — the drive is ~100× too slow, and it is kinematic

For a positive-displacement pump, exit velocity is fixed by geometry alone:

```
v_exit = v_plunger × (A_plunger / A_orifice) = v_plunger × 98.8   (15.9 mm bore, 1.6 mm orifice)
```

At the L12-210's **no-load 6.5 mm/s** — an unreachable ceiling — `v_exit = 0.64 m/s`, ballistic
range **4 cm**. At the actual operating point it is **0.078 m/s** and the charge falls out of the
barrel. **This cannot be fixed by thinning the fluid, opening the orifice, or buying more force.**
A 210:1 gearbox and a jet are mutually exclusive.

A 3 m throw needs ~5.4 m/s exit → 55 mm/s plunger → **21× the L12's no-load speed at 808 N**. The
whole 2 mL charge must leave in **~180 ms**.

**DESIGN_NOTES never computed an exit velocity or a range. That omission is why Mk2 passed its own
review. Every future revision must compute and report both.**

### Two further inputs that were wrong

**Fabri-Tac's viscosity is published and you used a value 5.3× low.** Beacon's SDS gives
**8,000 cps (8.0 Pa·s)**, 60 wt% volatiles, acetone 65–85 wt%:
https://beaconadhesives.com/cdn/shop/files/BEACON_FabriTac_SDS_2023_657ad5d7-a700-4d92-b5dd-1491e6f14541.pdf
At the true value the L12 needs **70.2 N for 12.6 s** — past its 62 N peak-power point, i.e.
**negative margin**, not the claimed 1.31×.

**The "do not dilute" rule in the Mk2 brief was wrong, and it was mine.** Stringing is *extensional*
elasticity set by polymer molecular weight, not shear viscosity. Thinning 1:1 drops shear viscosity
~16× while preserving filament behaviour, and acetone flash-off re-concentrates the strand in
flight. **Dilution to 1:1 is now permitted and encouraged.**

---

## 2. THE NEW DRIVE — spring + sear

Adopt the impulsive architecture. Sized for 2 mL, 3 mm orifice, 1:1 thinned fluid:

```
~72 kPa (10 psi),  ~14 N plunger force,  ~0.14 J stored
0.5 s shot,  ~0.8 m/s exit,  ~1.5-2 m throw
```

0.14 J is a modest compression spring. **Cock it by hand** through a lever, and fire it with a
**sear tripped by one of the two owned Corona DS239MG servos** — releasing a sear takes a few N·cm,
which is the job that servo is actually good at.

This deletes the Actuonix L12, the Pololu U3V70F6 and the DRV8833. It removes both specialty
vendor orders, saves ~$110, reuses an owned servo, and is the only variant that throws.

**Constraints:**
- Orifice **3 mm** (8–10 ga blunt needle). Force scales 1/r⁴ — this is why the numbers collapse.
- One shot per cock is acceptable. A second shot must be geometrically possible after re-cocking.
- The cocking lever must be operable one-handed, on the arm, and must not require tools.
- Spring energy is small; **do not** design a device that stores enough energy to injure.

If you judge a different impulsive mechanism better (over-centre toggle, elastic band, gas), take
it — but it must deliver ≥2 mL in ≤250 ms and you must show the velocity arithmetic.

---

## 3. MUST-FIX DEFECTS (every one was measured, not inferred)

### Will not print
| # | Where | Defect |
|---|---|---|
| 3.1 | `make_baseplate` L149–258 | **First layer is 35.1 mm² in 2 pieces** — two 0.29 mm strips holding 49 g of PETG. Modeled as a vault, concave face down, crown floating 8.58 mm. **7,841 mm² of down-facing surface below 45°**, including the entire 6,801 mm² skin-contact underside. No orientation fixes it. Make it a shallow chord, split it, or separate the soft interface. |
| 3.2 | `make_baseplate` L227–230 | Boost clip rail is a **floating island**, 771 mm³ attached by a single **13.5 mm²** butt face. Root cause: `add_support` L179–180 clamps `sample_y` into ±27.8, so anything outboard gets a bottom_z as if it sat on the plate edge. **Four of eight board rails and two of four LiPo posts are outboard.** |
| 3.3 | `make_baseplate` L201–205 | Both M3 insert pockets **break out of the +X end face** — Ø5.2 at x=116 needs x≤118.6, plate ends at 118. C-shaped, open pockets; inserts will not retain. |
| 3.4 | `make_bridge` L276–299 | Cross-section from x=10.5 to 29.5 is **4.50 mm² total — two 0.750 × 3.0 mm ligaments.** Strap slot and syringe lane eat the deck from both sides. Both barrel towers hang off this; a 5 N flick ≈ 700 MPa. |
| 3.5 | `make_switch_pod` L341–355 | The strap tunnel is **wider than the part**, so it deletes the floor; the pocket overshoots the top. What remains is a bare 18×18 open ring. No floor, no tunnel, no retention — the switch falls through. Also floats 9 mm from the hand, touching nothing. |

### Prints but will not work
| # | Where | Defect |
|---|---|---|
| 3.6 | stroke | **Jams at exactly 5.0 mm.** Yoke sweeps into the TP4056 clip rail (x=76) and the +Y syringe guide (x=80), and through the TP4056 itself: at 10 mm, 18.4 mm³ into the baseplate and **49.8 mm³ into the module.** Real shot = **0.99 mL**, half the requirement. `verify_model` only ever checked the retracted pose. |
| 3.7 | actuator mount | **The actuator is fastened to nothing.** Two 2 mm side fins, 0.45 mm clear, floating 3.2 mm above the shell, no rear abutment, no fastener. Swept 20 mm rearward with zero contact. The primary load path does not close. |
| 3.8 | `make_pusher_yoke` L324–338 | 3 × 6 mm web spanning a 17 mm offset → **σ ≈ 89 MPa** vs ~50 MPa PETG. ~2× over. Its only constraints are a pivot pin and a flat unguided face; it will rotate and cam off. No anti-rotation, no guide. |
| 3.9 | fluid path | **Does not connect.** Luer at (177.3, 0, 20.85); live barrel inlet at (178.0, **−6**, 21.6) — 6.09 mm off-axis. **0.2 mm ahead of the Luer is the blank flank of the barrel tower** — the syringe outlet is aimed at a solid wall. The `ptfe_line_owned` mockup sits 25–27 mm from both and was placed to pass the interference check. |
| 3.10 | syringe restraint | No axial reaction feature. Located by 2 mm side fins with 0.5 mm clearance; the finger flange is **not in the mockup at all**. First forward contact is the Luer tip crashing into the tower. The EPDM retainer claimed in the notes has no groove or notch on either side. |
| 3.11 | zero-clearance | Interference = 0.0 mm³ is hiding **tangency**: baseplate↔LiPo **0.050 mm** (notes say never clamp the pouch), baseplate↔switch **0.000**, baseplate↔actuator **0.000**, baseplate↔boost **0.000**. No board is captive — every one is a slot with no floor and nothing above. |
| 3.12 | bridge joint | Designed **0.30 mm air gap** between pad and bridge; two M3s clamping across a gap rock rather than clamp. 78 mm bridge, 6 mm overlap, barrels at the tip, through the 3.4 ligaments. |

### Wrong numbers / hygiene
- **Epsilon lifts** `+0.06`, `+0.01`, `+0.001` (L258, L321, L338) exist only to satisfy `z_min > -1e-6`
  and break tangency so volumes read 0.0. **Delete them and fix the checks instead.**
- `BOOST_SIZE` is 32 mm; the real U3V70F6 is **40.6 mm** — the true envelope collides 416 mm³ with the
  XIAO. The zero-interference result depended on an undersized proxy. (Moot if the boost is deleted.)
- `BARREL_OD = 2.4` is not a 14 ga needle (**2.11 mm**); the hub won't pass the 2.9 bore; a 1" needle
  leaves 25.4 mm where 26 is needed.
- Duplicated coordinate literals between `clip_specs` and `make_mockups`: (61,−28.5), (94,−31),
  (3,−27), (76,11.5), (56,28). `BARREL_GLOBAL_START_X = 178.0` silently encodes a sum of three other
  constants. `BRIDGE_FASTENER_X = 116` and the pad at `FOREARM_PLATE_LENGTH − 12.0` drift apart —
  that drift already produced 3.3.
- Docs vs geometry: barrel clearance is 0.5 mm not 0.25; the print gap is 0.30 not 0.35; foam is
  0.715 mm not 0.8 and non-uniform; "perforated towers" are solid blocks; "two forearm slot pairs"
  is a one-element loop.

---

## 4. THE VERIFICATION HARNESS MUST CHANGE

Mk2's suite passed all five Rank-1 defects. Rebuild it to include:

1. **Stroke sweep**, not one pose — check interference at every 0.5 mm through full travel.
2. **Minimum-gap check** as well as interference. Tangency (0.000 mm) must FAIL, not pass. Assert a
   real clearance for every non-contact pair and an explicit, justified contact list for the rest.
3. `abs(z_min) < tol`, not `z_min > -tol`.
4. **Connectivity / thin-feature check** — solid count cannot see a 13.5 mm² butt joint or a 0.75 mm
   ligament. Section each part and flag any cross-section under ~2 mm² or any ligament under 1.2 mm.
5. **First-layer footprint** check with a minimum area threshold.
6. **Overhang-angle** check on real sampled normals, reporting total area below 45°.
7. **Exit velocity and ballistic range** computed and printed, with the shot time.
8. Assert every mockup uses a **real, sourced** envelope, and print the source for each.

---

## 5. DELIVER

Same folder. Repaired model + assembly + `assembly_stl/` **including mockups** (Mk2 exported only
the 4 printed parts, so nothing could be rendered). Updated `DESIGN_NOTES.md` with the velocity
arithmetic front and centre. Updated `BOM_DELTA.md`.

**The cart has already been updated** — the builder now has, or is buying: 10 mL Luer-lock syringes
(30-pack), an 8/10/12/14 ga blunt needle assortment, a compression spring assortment, PETG and PLA
filament, 1" hook-and-loop strapping, closed-cell neoprene foam, and a multimeter. He already owns
the XIAO, TP4056, LiPo, both DS239MG servos, MT3608 boosts, tactile switches, wire, JST-PH, M3
screws, M3 heat-set inserts (5.0 × 4.0), EPDM O-rings, PTFE tube, Fabri-Tac and acetone.
**Design to that inventory.** If you need something else, it goes in BOM_DELTA with a reason.

Targets unchanged: **≤25 mm wrist profile, ≥1.5 mL per shot, ≤6 printed parts** — plus the new one:
**≥1.5 m throw, which means ≥2 mL in ≤250 ms.**

Three auditors will run again and will keep running until they have no substantive findings.
Work autonomously; do not stop to ask questions.

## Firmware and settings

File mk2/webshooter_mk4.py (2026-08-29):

#!/usr/bin/env python3
"""
Web-Shooter Mk5 (in progress, still in the mk4 module name) — parametric CadQuery model.

MK5 STATUS — ROUND 4 OF 5 COMPLETE. READ THIS BEFORE EDITING.
-------------------------------------------------------------
ROUND 4 DREW THE RECOCK ACTUATOR AND MADE THE HARNESS MEASURE IT.

Until this round the headline requirement rested on a 1.804 mm lever arm that no
part possessed. `N_BITES = 2` and

    WINCH_RADIUS_MM = PLUNGER_STROKE / (RECOCK_SWEEP_RAD * N_BITES)

produced a number, check_recock_budget divided the same three constants back out
of it, and the gate reported 2.24x on a mechanism whose only reach toward the
carriage was an 0.850 mm sliver of bounding-box corner. Two bites also demanded a
half-cock hold that nothing in the model provides (defect 12).

DELETED: N_BITES, WINCH_RADIUS_MM, RECOCK_PEAK_TORQUE_N_MM, the rocker, its pin,
the hand-lever hex stub (architecture C's free fallback goes with it, and that is
a real loss), the winch servo's horn and pushrod.

DRAWN INSTEAD, all of it geometry:
  * winch_drum     a PROFILED SCROLL on the winch servo's output shaft. Radius
                   falls from 7.00 to 1.98 mm through the sweep, so the torque is
                   flat instead of ramping with the spring. Solved from
                   ds/dphi = T/F(s), capped at R_max over the first phi0 radians,
                   phi0 by bisection. Machined aluminium, not printed - the waist
                   is 1.7 mm from the axis and only exists because the hub is in
                   a different y band from the cable groove.
  * winch_shaft    the servo's own spline, so "the drum is on a shaft" is a
                   measurable statement rather than a caption.
  * recock_cable   Ø0.6 UHMWPE, tangent to the drum groove and swaged over
  * recock_anchor_pin  a Ø2 dowel through
  * a FORK on the carriage's rear face, full height so it prints, with 4.3 mm of
                   pin journalled in material. That number replaces 0.850 mm of
                   bounding-box corner.
  * a winch servo CRADLE on the baseplate, at located-fit clearance.

MEASURED RESULT (harness, not this file): radius read off the drawn drum at 33
angles; peak 97.0 N.mm at the servo shaft against 150 usable, 1.55x, flat to
within 0.5% across the sweep; one sweep draws 10.468 mm against a 10.073 mm
stroke; drum turns a full revolution clear of every other body.

WHAT IT COST
  * THE SWEEP IS NOW 170 deg, not 160. At 160 the solved profile is 1.45x and no
    choice of R_max recovers it. This is the single bench measurement the whole
    architecture hangs on - servodatabase says the DS239MG turns 40 deg.
  * THE LIPO MOVED FORWARD 86 mm, because the tail is where the drum has to be.
  * The hand-cock fallback is gone.
  * The drum is CANTILEVERED on the servo's output shaft: 37 N at ~5 mm is
    ~190 N.mm of bending on a bushing that was not designed for it, and there is
    nowhere to put an outboard bearing (the push-rod occupies y = -19..-13 at
    exactly the shaft height). UNRESOLVED - see the round 4 notes.

ROUND 3 WAS A GEOMETRY ROUND, AND THE DEVICE NOW FIRES FIVE TIMES.

Rounds 1 and 2 built the instrument and left the part untouched; the harness
consequently got better at describing a machine that could not fire once. Round
3 changed no check. The whole diff is drawn geometry, and the number it moved is
the one that matters:

    shot 1  10.07 of 10.07 mm  ->  2.00 mL      (was 3.00 mm -> 0.60 mL)
    shot 2  10.07 of 10.07 mm  ->  2.00 mL      after a re-cock to the same X
    shots 3-5 likewise; 10.00 mL total, stopped by nothing

WHAT WAS DRAWN
  * THE FRAME GREW REARWARD, 64.0 mm of it, and FRAME_X0 is now DERIVED from the
    push-rod's tail rather than assumed to be 0. The frame is 238 mm along the
    forearm against Mk4's 174. That is the largest single cost this design
    carries and it is a length, not a height.
  * THE STATION MAP WAS RE-ROOTED AT THE SYRINGE. The old chain grew forward
    from SPRING_X0 = 8.0 and could therefore never give the stroke room that has
    to come out of the back; the 7.028 mm deficit was arithmetic, not spacing.
    GRIP_SPAN_DEFICIT_MM is now -0.350 and asserted <= 0.
  * THE CARRIAGE IS BORED ON THE ROD - spring counterbore, rod bore, drive-plate
    pocket, return-spring pocket - so the three purchased bodies that were drawn
    inside solid material (338.23 + 138.56 + 85.42 mm3) now have the pockets
    they always needed. Push pad and thumb tab deleted: both served a mechanism
    Mk5 does not have.
  * THE ANTI-RETURN PLATE HAS AN ABUTMENT. It carried 37 N into air 2.10 mm from
    anything solid. It is now Ø18 against the drive plate's Ø14 and beds on an
    annulus of a bored wall on the baseplate, so the Ø14 drive plate passes
    through the middle at full stroke while the reaction lands on printed
    material.
  * THE WINCH ROCKER LEFT THE CARRIAGE LANE, into the pocket the shortened rails
    vacate behind the cocked carriage, on printed pin bearings.

WHAT IT COST, STATED RATHER THAN ABSORBED
  A carriage that CONTAINS the rod is taller than one that shoves a flange:
  carriage top 16.40 -> 17.95 mm, and since SEAR_CONTACT_Z derives from it, the
  pawl, tower and stack all rise with it. Wrist profile 35.50 -> 37.05 mm
  against a 25 mm target. The tower alone is 32 of those millimetres, so the
  profile is a sear-architecture problem for round 4/5, not a spring-placement
  one.

WHAT ROUND 3 DID NOT TOUCH (deliberately - these are round 4/5)
  * check_grip_release's return sweep starts from the COCKED pose and retracts a
    further full stroke into a spring drawn at its cocked length. The carriage's
    cocked pose IS its rearmost; the return stroke runs fired -> cocked, which
    check_multishot's own stepper walks successfully five times. The check is
    posed wrong, and repairing checks was reserved for round 4.
  * push_rod <> grip_plate_* "overlap 0.07 mm3" is the BITE - the design
    requires 0.10 mm of diametral interference - reported as a clearance defect.
  * the servo cannot open the sear (240 vs 150 N.mm): architecture B.
  * servo mounts, horns, cradle screws and the outlet adapter are step 4/7/8.

DONE:
  1. HARNESS BEFORE MODEL. check_spring_buckling, check_servo_torque,
     check_one_way_grip, check_multishot, check_recock_budget,
     check_wrist_profile and check_piston_containment were added to
     verify_independent.py and run against the UNCHANGED Mk4 first. All seven
     fired, and their numbers independently reproduced the brief's hand
     arithmetic: 642 N.mm to release the sear against 150 available, shot 2
     delivering 0.79 mL, slenderness 6.48 with a 32% pilot. A check written
     after the fix has never been seen to fail; these were.
  2. PHYSICS. TARGET_RANGE_M 1.5 -> 1.60 (off the knife edge against the
     harness's own >= 1.5 gate); OUTLET_BORE is now DEFINED AS CANNULA_ID_MM,
     so the design bore and the sizing bore are one number and cannot drift
     apart again; cartridge 5 mL -> 10 mL for five 2 mL shots.
  3. MOCKUPS. 7 bodies -> 26. Barrel is a tube, finger flange an annulus, and
     the piston, push-rod, both grip plates, two servos, two horns, two
     pushrods, the rocker and its pin, the hex hand-lever stub, the sear
     torsion spring, the cannula, hub and O-ring, and the cradle screws are all
     present. Failure count rose 21 -> 42, which is the point.

NOT DONE — steps 4 to 9, in this order:
  4. fluid spine: front abutment, split cradle, cannula collar, muzzle cap
  5. push-rod, grip plates, rear abutment, spring, tail shroud
  6. carriage bored on the rod, carrying the rack
  7. sear and trip servo  (do this BEFORE the winch: never leave the build able
     to cock but not certifiably hold a compressed 37 N spring on a wrist)
  8. cocking winch
  9. edge treatment

ONE MEASURED CONSEQUENCE ROUND 1 SURFACED AND DID NOT SOLVE:
  the push-rod's tail reaches x = -48.4 while the baseplate starts at x = 0.
  Five shots from a 10 mL cartridge require FILL_LEN = 50.4 mm of rod behind
  the spring seat, or the spring loses its pilot on the last shots. The frame
  must grow rearward by ~52 mm, or the mechanism shift forward, or the shot
  count drop. That is a length along the forearm, not a height on the wrist,
  but it is a real cost of the cartridge choice and it is not yet paid.

WHY MK4 EXISTED
---------------

WHY MK4 EXISTS
--------------
Mk3 had three independent mechanism failures and an energy shortfall, all found by
independent audit after its own harness reported `failures: []`:

  * the sear was inverted — the load line sat 5.9 mm below the pivot, so the spring
    torqued it toward release. It fired itself the instant it was cocked.
  * the sear also sat in the carriage's path — 60 mm3 of interference mid-stroke.
  * the cocking lever was over-constrained (round pin in round hole, no slot) and
    achieved 0.096 mm of the 10.07 mm it needed.
  * the drive was energy-starved: 0.179 J stored against 0.276 J needed just to
    push the charge through the syringe's own Luer taper.

Mk4 does not patch those. It removes the conditions that created them:

  1. THE LUER TAPER IS CUT OFF and replaced by a bonded 4 mm x 12 mm outlet.
     Work falls from 0.276 J to 0.092 J — half the stored energy, with margin.
  2. A 5 mL SYRINGE replaces the 10 mL. Same 2 mL shot (bore does not affect exit
     velocity: v = V/(t*A_o), the bore cancels), but the longer stroke drops peak
     spring force to 11.2 N.
  3. the peak spring force (16.3 N, see mk4_params.json) is a thumb pull, so the cocking lever and its two pins are deleted.
     A broken mechanism removed rather than repaired.
  4. THE SEAR ENGAGES THE CARRIAGE'S REAR FACE. Firing moves the carriage away
     from the sear, so a stroke jam is not geometrically possible. The pivot sits
     above and behind the contact so the spring load torques the tooth deeper into
     engagement — verified numerically in `sear_moment_check()`, not asserted.

Every part is prismatic and extruded from its own bed plane, which is also what
fixes Mk3's unsupported islands and undersized first layers.

Run:  python webshooter_mk4.py          # exports STEP + STL per part
Check: python verify_independent.py --model webshooter_mk4
"""
from __future__ import annotations

import math
import os
import sys
from dataclasses import dataclass
from typing import Dict

import cadquery as cq

OUT = os.path.dirname(os.path.abspath(__file__))

# =============================================================== fluid physics
# All derived, none declared. These drive the geometry below.
FLUID_VISCOSITY_PA_S = 0.50      # 1:1 thinned Fabri-Tac (SDS 8000 cP neat)
SHOT_VOLUME_ML = 2.0

# (Mk5) TARGET_RANGE_M 1.5 -> 1.60.
# The harness fails the design when the range at the REAL cannula drops under
# 1.5 m. Targeting exactly 1.5 put the design on a floating-point knife edge
# against its own acceptance gate: a rounding step in either direction is the
# difference between pass and fail, and three revisions have been decided by
# that last decimal. 1.60 is the same design with the gate off the edge.
TARGET_RANGE_M = 1.60
G = 9.81

EXIT_VELOCITY_M_S = math.sqrt(TARGET_RANGE_M * G)        # 3.962 m/s

# (Mk5) THE DESIGN BORE AND THE SIZING BORE ARE NOW ONE NUMBER.
# Mk4 drew a 4.00 mm outlet and then sized the spring against a 3.429 mm
# cannula, so every derived quantity in the file existed in two versions and
# the discrepancy - 0.0921 J against 0.1705 J - has been rediscovered by an
# independent reviewer in three consecutive revisions. There is no bonded 4 mm
# adapter in Mk5 (defect 10: no bonded joint anywhere in the fluid path), so
# the only bore the fluid ever sees is the replaceable cannula's. Declare that
# once and derive everything from it; the two numbers cannot drift apart
# because there is only one of them.
CANNULA_ID_MM = 3.429                                    # real 8 ga blunt tip
OUTLET_BORE = CANNULA_ID_MM
OUTLET_LENGTH = 12.0                                     # mm of wetted bore

_r = OUTLET_BORE / 2000.0
_V = SHOT_VOLUME_ML * 1e-6
OUTLET_DP_PA = 8 * FLUID_VISCOSITY_PA_S * (OUTLET_LENGTH / 1000.0) * EXIT_VELOCITY_M_S / (_r * _r)
FLOW_WORK_J = OUTLET_DP_PA * _V
SHOT_TIME_S = _V / (EXIT_VELOCITY_M_S * math.pi * _r * _r)   # derived
BALLISTIC_RANGE_M = EXIT_VELOCITY_M_S ** 2 / G

# ------------------------------------------------------------------ cartridge
# (Mk5) 10 mL NORM-JECT, back from Mk4's 5 mL.
#
# Mk4 went 10 -> 5 mL to cut peak spring force and stack height. With a ratchet
# doing the recocking the force argument is gone - the servo does that work, and
# it does it in N small bites rather than one pull. What the 10 mL buys is the
# headline requirement: 5 shots of 2 mL per fill against the 5 mL's 2.5.
#
# It costs stack height, and that cost is not hidden: the barrel is 3.30 mm
# fatter than the 5 mL, which is a straight 3.30 mm onto the wrist profile.
# check_wrist_profile measures the whole assembly against the 25 mm target and
# will say so.
#
# BENCH FIRST: these are catalogue figures for a 10 mL NORM-JECT and the brief's
# step 0 requires the actual barrel to be measured with calipers before anything
# is cut. Bore, OD and length are all parametric on these three lines.
SYRINGE_BORE = 15.90            # UNVERIFIED - measure the real barrel
SYRINGE_WALL = 0.55             # UNVERIFIED - measure the real barrel
SYRINGE_OD = SYRINGE_BORE + 2 * SYRINGE_WALL             # 17.00
SYRINGE_BARREL_LEN = 88.0       # UNVERIFIED - measure the real barrel
SYRINGE_FLANGE_OD = 26.0        # UNVERIFIED
SYRINGE_FLANGE_T = 2.5          # UNVERIFIED
SYRINGE_CAPACITY_ML = 10.0
SHOTS_PER_FILL = int(SYRINGE_CAPACITY_ML // SHOT_VOLUME_ML)      # 5

_A_p = math.pi * (SYRINGE_BORE / 2000.0) ** 2
PLUNGER_STROKE = _V / _A_p * 1000.0                      # 16.43 mm
PLUNGER_FORCE_N = OUTLET_DP_PA * _A_p                    # 5.60 N
PLUNGER_ROD_OD = 6.0
PLUNGER_THUMB_OD = 18.0
PLUNGER_THUMB_T = 2.5

# ----------------------------------------------------- the sizing restriction
# (Mk5) THERE IS NO LONGER A DISCREPANCY TO RESOLVE HERE.
#
# Mk4 drew a 4.00 mm adapter bore and sized the spring against the 3.429 mm
# cannula that would actually be fitted, so the file carried two sets of every
# derived number and three consecutive independent reviews rediscovered the gap
# between them. Mk5 deletes the bonded adapter entirely (defect 10 wants a
# serviceable joint, not a glued one), so the cannula IS the outlet and
# OUTLET_BORE is defined as CANNULA_ID_MM above. FLOW_WORK_J and CANNULA_WORK_J
# are therefore the same computation on the same number, and SIZING_WORK_J is
# not a max over a disagreement - it is a max over an identity. The assert
# below is what keeps it that way if anyone re-opens the bore.
_rc = CANNULA_ID_MM / 2000.0
FLOW_RATE_M3_S = EXIT_VELOCITY_M_S * math.pi * _r * _r
CANNULA_DP_PA = (8 * FLUID_VISCOSITY_PA_S * (OUTLET_LENGTH / 1000.0)
                 * FLOW_RATE_M3_S / (math.pi * _rc ** 4))
CANNULA_WORK_J = CANNULA_DP_PA * _V
SIZING_WORK_J = max(FLOW_WORK_J, CANNULA_WORK_J)
assert abs(FLOW_WORK_J - CANNULA_WORK_J) < 1e-9, (
    "the design bore and the sizing bore have drifted apart again: "
    f"{FLOW_WORK_J:.6f} J vs {CANNULA_WORK_J:.6f} J")

# --------------------------------------------------------------------- spring
# Sized from the derived sizing work with margin, not chosen then justified.
SPRING_MARGIN = 1.45
SPRING_ENERGY_J = SIZING_WORK_J * SPRING_MARGIN
SPRING_PEAK_N = 2.0 * SPRING_ENERGY_J / (PLUNGER_STROKE / 1000.0)
SPRING_RATE_N_MM = SPRING_PEAK_N / PLUNGER_STROKE
SPRING_OD = 8.0
SPRING_WIRE = 0.9
# (Mk5) The 10 mL bore cuts the stroke from 16.43 mm to 10.07 mm, so the spring
# gets shorter as well. Free length is set from the stroke plus solid height
# plus a working margin rather than left at Mk4's 46 mm, which would now be
# 4.6 coil diameters of unused length sitting on the wrist.
SPRING_SOLID_LEN = 9.0                                   # ~10 active coils
SPRING_FREE_LEN = 34.0
SPRING_COCKED_LEN = SPRING_FREE_LEN - PLUNGER_STROKE
assert SPRING_COCKED_LEN > SPRING_SOLID_LEN, "spring goes solid before full cock"


# ============================================== (Mk5) THE ACTUATORS AND THE WINCH
# Defect 3: `grep servo` across Mk4 found only comments. There was no mount, no
# horn, no pushrod and no linkage, and BOM_DELTA.md said "servo mounting as
# shown" while nothing was shown. Every number a servo check could possibly want
# is declared here, in one place, with its provenance.
#
# BENCH FIRST, NOTHING CUT. Step 0 of the build order requires six measurements
# before any of this is trusted. The two that decide the architecture are marked
# BENCH: servodatabase lists the DS239MG's sweep as 40 deg and its body as
# 30 x 10 x 34.5 mm, and a 10 mm width on a 22 g servo is internally implausible.
# Defect 3 exists because nobody ever held the part.
SERVO_STALL_N_MM = 4.6 * 98.07        # 4.6 kg.cm at 6 V, DS239MG   BENCH: stall
SERVO_HORN_R_MM = 9.0                 # horn pin radius on the output shaft
SERVO_L, SERVO_W, SERVO_H = 30.0, 13.0, 34.5   # BENCH: measure the real body
SERVO_MOUNT_T = 3.0                   # printed mount wall the body sits in
SERVO_SHAFT_DX = 9.0                  # shaft offset along the body from its end

# =========================== (Mk5 round 4) SINGLE-SWEEP SCROLL WINCH
#
# WHAT WAS DELETED AND WHY. Rounds 1-3 carried `N_BITES = 2` and a
# rocker-and-pawl winch that drew the stroke in two equal bites. Two bites is
# what forced
#       WINCH_RADIUS_MM = PLUNGER_STROKE / (sweep * N_BITES) = 1.8035 mm
# and 1.8035 mm was a NUMBER, not a feature: no part in the file had a radius,
# a pin, a groove or a face at 1.8 mm from any shaft, and the rocker's only
# reach toward the carriage was an 0.850 mm corner sliver of bounding-box
# overlap. Worse, two bites needs the carriage HELD at half cock between them,
# and nothing in the model holds it - defect 12, which the brief already lists.
# So N_BITES, WINCH_RADIUS_MM and the rocker are gone, and with them the
# hand-lever hex stub (architecture C's free fallback): there is no longer a
# rocker shaft to put it on, and the drum sits in a pocket a lever cannot reach.
# That is a real loss and it is stated rather than absorbed.
#
# WHAT REPLACES IT. One sweep. A profiled scroll drum on the winch servo's
# output shaft winds a UHMWPE cable that ends on an anchor pin through a fork on
# the carriage's rear face, and one 160 deg sweep draws the whole 10.073 mm and
# lets the sear catch at full cock.
#
# THE ARITHMETIC, AND WHY THE DRUM IS PROFILED RATHER THAN ROUND.
# A CONSTANT radius closes the energy balance and fails the instant:
#       r_const   = stroke / sweep            = 3.607 mm
#       peak      = F_cocked * r_const        = 134 N.mm at the servo
# against 150 N.mm usable - 1.12x at the worst instant of the cycle. Raising the
# radius makes the peak worse; lowering it makes the sweep too short to draw the
# stroke. The fix is SHAPE. The spring's resistance rises linearly with the
# draw, so the drum's radius is made to FALL as the draw proceeds: the cable
# leaves at a large radius while the spring is soft and at a small one while it
# is stiff, and the torque is flat instead of ramping. The schedule below is
# solved, not fitted: constant torque T against F(s) = k*s + drag gives
#       ds/dphi = R = T / F(s)   ->   (k/2)s^2 + drag*s = T*(phi - phi0) + const
# capped at WINCH_R_MAX_EFF over the first phi0 radians, because the true
# constant-torque profile needs an infinite radius where the force is zero.
# phi0 is then the root that makes the cap and the constant-torque arc draw
# exactly PLUNGER_STROKE between them, found by bisection below.
# THE SWEEP IS 170 DEG AND THAT IS A DECISION, NOT A ROUNDING.
# At 160 deg the solved profile peaks at 104 N.mm against 150 usable - 1.45x,
# under the 1.5x gate - and no choice of WINCH_R_MAX_EFF recovers it: the peak
# is set by the sweep and the over-travel, and R_max moves it by under 2%.
# 170 deg gives 1.55x, 180 deg gives 1.65x. The brief's own table says the same
# thing (160 -> 1.4x, 180 -> 1.5x, before the drag term this model carries).
# THIS IS THE SINGLE BENCH MEASUREMENT THE WHOLE ARCHITECTURE HANGS ON:
# servodatabase lists the DS239MG's rotation as 40 deg, which if true kills the
# one-sweep winch outright and the fallback is a bigger drum on a geared servo,
# not a tweak to this profile. Measure it over 500-2500 us before cutting.
RECOCK_SWEEP_DEG = 170.0              # BENCH: measure over 500-2500 us PWM
RECOCK_SWEEP_RAD = math.radians(RECOCK_SWEEP_DEG)

# The load the drum works against. NOT just the spring: the drive plate's
# return spring is being squared and the carriage is sliding in its rails, and
# a recock budget that pretends those are zero is a budget with a free lunch in
# it. 3.0 N is the drive plate's own return spring taken at full value plus
# nothing for rail friction - BENCH: drag the cocked carriage on a scale.
RECOCK_DRAG_N = 3.0
WINCH_EFFICIENCY = 0.85               # cable stiffness over the drum + bearing

WINCH_CABLE_D = 0.6                   # Ø0.6 UHMWPE braid, ~200 N break vs 37 N
WINCH_R_MAX_EFF = 7.0                 # cable PITCH radius at the start of sweep
WINCH_GROOVE_DEPTH = 0.35             # groove floor sits this far under the rim
WINCH_GROOVE_W = 0.8                  # groove width, y

# OVER-TRAVEL. The sweep must not draw EXACTLY the stroke. The sear tooth has
# to have somewhere to drop into once the lug has passed under it, cable braid
# creeps a few tenths under load, and a profile solved to the stroke to the last
# micron fails an integration of its own drawn radius by rounding. 0.40 mm is
# the tooth's own gap over the lug (SEAR_TOOTH_GAP is 0.8; half of it is enough
# to catch) and it is drawn into the drum, not asserted about it.
WINCH_OVERDRAW_MM = 0.40
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

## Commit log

2026-08-27 Web-shooter: Mk1 archive, Mk2 open-frame design, Mk3 rebuild in progress
    Mk1 (archive_mk1/): enclosure around a 10 mL fragrance pump. Scrapped after three
    independent audits found 96% cabin packing, three geometrically broken parts, and a
    0.1 mL dose that cannot form a strand.
    Mk2 (mk2/): open-frame redesign — curved baseplate, exposed components, barrels over
    the back of the hand, syringe as reservoir/pump/seal. Hit all size and volume targets
    (21.7 mm profile, 1.99 mL, 4 printed parts) but audits found the drive is ~100x too
    slow to throw fluid, plus twelve measured geometry defects.
    Mk3 (in progress): replaces the linear actuator with a hand-cocked spring and a
    servo-tripped sear.
    Co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
    [barrel_bridge.step, barrel_bridge.stl, baseplate.step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]
2026-08-27 Remove Mk1 archive from working tree
    Superseded by the Mk2/Mk3 open-frame design. All 107 files remain recoverable
    from history: git checkout 85bd6a2 -- archive_mk1
    Claude-Session: https://claude.ai/code/session_01T5aUqbZHoxCauoXhVR4LhD
    [barrel_bridge.step, barrel_bridge.stl, baseplate.step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]
2026-08-27 Mk3: spring + sear drive replaces linear actuator
    Exit velocity 4.10 m/s (was 0.078), ballistic range 1.71 m, shot 2.0 mL in 69 ms.
    All four targets met: 24.3 mm wrist profile, 2.0 mL/shot, 6 printed parts, 1.71 m throw.
    Drive is a hand-cocked compression spring released by a DS239MG-tripped sear.
    Deletes the Actuonix L12, Pololu U3V70F6 and DRV8833 - no specialty orders.
    Fluid path now actually connects: axial gap 0.0, axis offset 0.0 (was 6.09 mm
    off-axis and aimed at a solid tower flank).
    Verification harness rebuilt per audit: full stroke sweep, minimum-gap checks
    where tangency fails, mockup source/confidence table, and exit velocity plus
    ballistic range computed every run.
    Co-Author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
    [barrel_bridge.step, barrel_bridge.stl, baseplate.step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]
2026-08-28 Add bl.py: headless CLI for the Blender scene, plus Mk3 visualization
    bl.py drives the .blend from a terminal - inspect (ls/tree/info/stats/anim/
    materials), measure (min vertex gap, bbox gap, collection bounds), control
    visibility, render (named camera, arbitrary az/el, turntable, all cameras),
    and export. Name matching folds case and punctuation so em-dashed collection
    names resolve, and collections work anywhere an object name does.
    Visualization from Codex: 220 objects, 4 cameras, animated 1-72 at 60fps with
    timeline markers for each phase of the cock/trip/fire cycle.
    Claude-Session: https://claude.ai/code/session_01T5aUqbZHoxCauoXh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
    [webshooter_mk3_visualization.blend]
2026-08-28 Add verify_independent.py: an audit harness not written by the geometry author
    Three revisions shipped with a self-check reporting failures:[] while independent
    audits found the parts unbuildable. The arithmetic was never wrong - the checks
    could not see the defects: exclusions by name, single-pose sampling, missing
    pairings, thresholds set above the measured defect, section sampling coarser than
    the ligament gate it enforced, and a fluid-path check that compared constants to
    themselves.
    This harness takes the opposite stance on each: no name exclusions, no allowlist,
    sweeps instead of poses, 0.5 mm sections, 0.4 mm island scan, and physics derived
    from stored spring energy rather than read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
2026-08-28 Mk4: cut the Luer, 5 mL cartridge, self-holding sear, no cocking lever
    Mk3's three mechanism failures are removed rather than patched:
    - The syringe's own Luer taper was the flow bottleneck at 0.276 J. It is cut off
    and replaced by a bonded 4 mm x 12 mm outlet: 0.0921 J, against 0.1335 J stored.
    Margin 1.45x, where Mk3 was short by 1.5x.
    - A 5 mL cartridge replaces the 10 mL. Exit velocity is V/(t*A_o), so bore does
    not affect it - but the longer stroke drops peak spring force to 16.3 N.
    - 16.3 N is a thumb pull, so the cocking lever and its two pins are deleted. The
    lever that could only achieve 0.096 mm of 10.07 mm no longer exists.
    - The sear now catches the carriage's REAR face,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
    [mk4_baseplate.step, mk4_baseplate.stl, mk4_carriage.step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]
2026-08-28 Mk4: curved baseplate, animated Blender scene, slotted-action fix in bl.py
    Wrist curve: a shallow cylindrical relief cut into the UNDERSIDE inboard of a
    flat rim, rather than a full vault. Mk3's vaulted plate printed on two hairline
    edges (35 mm2 first layer). This keeps a flat contact rim, measures 3954 mm2 of
    first layer across two strips, and removes 9.9 cm3 of plastic. R=95 mm with a
    2.2 mm sagitta is the honest limit before the rim stops being printable - a true
    50 mm arm crown would need 9 mm and leave no rim at all.
    Caught a sign error on the way: centring the cutting cylinder above the plate
    hollows the EDGES, which is the opposite of a wrist curve.
    Animation: 78 frames at 60 fps w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
    [mk4_baseplate.step, mk4_baseplate.stl, mk4_carriage.step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]
2026-08-28 Pre-publication red-team fixes: license, safety, honest status
    - Add MIT LICENSE and no-warranty disclaimer
    - README: safety section (solvent, no mechanical safety/firmware, cocking
    off-arm, LiPo), Mk4 as current, list the open independent-audit failures,
    reproduce steps; drop references to deleted archive_mk1
    - verify_independent.py: add --model flag (docs promised it), default to
    Mk4, exit with the real return code via os._exit
    - DESIGN_NOTES: "zero verifier failures" now scoped to the self-check
    - Scrub absolute local paths from briefs and PNG metadata
    Claude-Session: https://claude.ai/code/session_019iEB7LtForyioVx8ZegDQN
    [mk4_baseplate.step, mk4_baseplate.stl, mk4_carriage.step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]
2026-08-28 Mk4 bug fixes, and a sear-release check that catches my own design
    Fixed:
    - carriage push pad was PLUNGER_THUMB_OD (18 mm) wide against a 14.9 mm clear
    span between its own rails - it scraped both. Sized to the body.
    - bridge insert bosses at y=+/-16 ran straight through the outlet adapter.
    Moved outboard to +/-26.
    - sear post hung 8.35 mm off the plate edge. The pawl is now a flat part on a
    proper journal: an r=3 shoulder up to the pawl plane, then an r=1.6 pin
    through the hub, instead of an r=3 post through an r=1.75 hole.
    - sear tooth entered the carriage lug by 1 mm. It now abuts the lug face.
    - fluid lane moved inboard (FLUID_Y -20 -> -16) to make room outboard for the
    pivot w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
    [mk4_baseplate.step, mk4_carriage.step]
2026-08-28 Mk4 lifting pawl: sear can now actually release
    The vertical-axis pawl could not get out of its own way - check_sear_release
    found no angle under 90 deg that cleared the carriage stroke, because the arm
    crossed the lane the carriage travels along.
    Replaced with a lifting pawl on a transverse Y pivot. Self-holding condition
    derived rather than asserted: M_y = r_z*F_x and dz = -dtheta*r_x, so the tooth
    moves DOWN under load iff r_x and r_z share a sign - i.e. the tooth must sit
    below AND behind the pivot. It does: r_x -9.0, r_z -13.4, M_y -218 N.mm.
    Release now clears at 45 deg, a realistic servo throw.
    Four bugs found and fixed on the way:
    - lat came out negative (tooth is inboard of the pi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
    [mk4_baseplate.step, mk4_baseplate.stl, mk4_carriage.step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]
2026-08-28 Mk4: zero failures at full resolution after the implementer/reviewer/director loop
    Three rounds ran (round 4 died on a login expiry). Net result: the full-resolution
    harness passes every check, where the baseline was 6 failures.
    Geometry fixes by the loop:
    - all three static overlaps closed, and abutment PROVEN rather than assumed: the
    tooth bears on the lug over 22.00 mm2 of coplanar face at zero shared volume
    - sear engagement height is now DERIVED. SEAR_CONTACT_Z was hand-set to
    body_top+0.6, which put the tooth inside the push pad; each carriage station
    now declares its height and the lug is solved to reach the tooth
    - the pivot-pin bore never touched the tower: Workplane('XZ').ex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
    [mk4_baseplate.step, mk4_baseplate.stl, mk4_carriage.step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]
2026-08-28 Mk5 presentation scene: animated, restrained palette, brass on the working parts
    Built from the verified Mk4 geometry (harness passes zero failures at full
    resolution). Cameras: hero, mechanism, plan. Animation runs 92 frames at 60 fps
    with markers for rest, cock, catch, hold, servo trip, fire and reset; the pawl
    lifts through the MEASURED 25 deg release angle rather than a guessed one.
    Framing fixes: the forearm reference no longer drags the auto-framing, labels
    fan along the device length instead of stacking, and labels render only on the
    hero shot - on the mechanism and plan views the leader lines crossed the subject
    they were pointing at.
    [mock_brass_muzzle.stl, mock_compression_spring.stl, mock_ds239mg_servo.stl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]
2026-08-28 Restore purchased-part bodies to the model: the harness was starved, not gamed
    Two independent acceptance reviews both returned NOT READY and both traced every
    blocking defect to the same cause. verify_independent.py guards its mockup load
    with 'if hasattr(M, "mockups")'. Mk4 defined none - the guard silently skipped,
    and bodies held only the five printed parts. The syringe, plunger, spring, servo
    and pins appeared in no check at all. One reviewer: 'the harness was not gamed by
    editing - it was starved by the model.'
    That is the same failure class the harness exists to prevent, one level up: I
    fixed checks that could not see defects in printed parts, then drew the boundary
    so it excluded ev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
    [mk4_baseplate.step, mk4_carriage.step, mk4_outlet_adapter.step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]
2026-08-29 Mk5 multi-shot: caulk-gun ratchet + winch recock, 5 shots per fill
    Five rounds of architect/implementer/reviewer/director. The independent reviewer
    verified multi-shot working in round 5 - the first time any revision has fired
    more than once.
    Architecture:
    - CAULK-GUN RATCHET. Two grip plates (drive + anti-return) on a push rod. The
    plunger never retracts; each cycle the drive plate grips further back and
    advances it one stroke. This is what the fixed carriage window could never do.
    - WINCH RECOCK. A cable winch with drum, clutch and rewind spring pulls the
    carriage back between shots, so the device re-cocks itself.
    - TWO SERVOS, both already owned (the cart has a 2-pack). One winches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
    [mk4_baseplate.step, mk4_baseplate.stl, mk4_carriage.step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]
2026-08-29 Rebuild the Blender scene from the multi-shot geometry
    The scene was still showing the single-shot Mk4. Re-exported all 34 bodies from
    the current model - 5 printed parts plus 28 mockups including both servos, the
    winch train, the ratchet grip plates and the cannula - and re-rendered.
    Note: I clobbered the agents' rewritten build_mk5_viz.py with a regex edit
    written for the old 5-tuple INFO format; theirs uses a richer principled()
    material system. Reverted to theirs, which renders correctly.
    [mock_brass_muzzle.stl, mock_cannula.stl, mock_cannula_hub.stl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]
2026-08-29 Fix viewport shading: set it on bpy.data.screens, not window_manager.windows
    The scene opened in flat Solid shading with no materials or lighting, which read
    as 'low res'. Cause: the shading loop iterated bpy.context.window_manager.windows,
    and in background mode (-b) there are no windows, so it was a silent no-op and
    the saved file kept Blender's default Solid shading.
    bpy.data.screens exists in background mode and persists into the .blend. Also
    turned off relationship lines, extras gizmos and the floor grid, which were
    drawing over the model in the screenshot.
    [webshooter_mk5.blend]
2026-08-29 Fix the blurry viewport: flat shading and finer tessellation
    Two causes, both mine.
    1. Blanket smooth shading. The importer set use_smooth=True on every polygon of
    every part, which interpolates normals across hard edges and turns crisp
    machined boxes into blobs. Mechanical parts want flat shading; the facets ARE
    the geometry. Switched to use_smooth=False.
    2. Coarse STL export. Bodies were tessellated at 0.04-0.05 mm chord tolerance,
    so cylinders showed visible faceting. Re-exported all 33 at 0.012 mm.
    Edges are crisp now - the winch drum, the ratchet plates and the cartridge read
    as machined parts rather than melted ones.
    [mock_cannula.stl, mock_cannula_hub.stl, mock_cannula_oring.stl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]
